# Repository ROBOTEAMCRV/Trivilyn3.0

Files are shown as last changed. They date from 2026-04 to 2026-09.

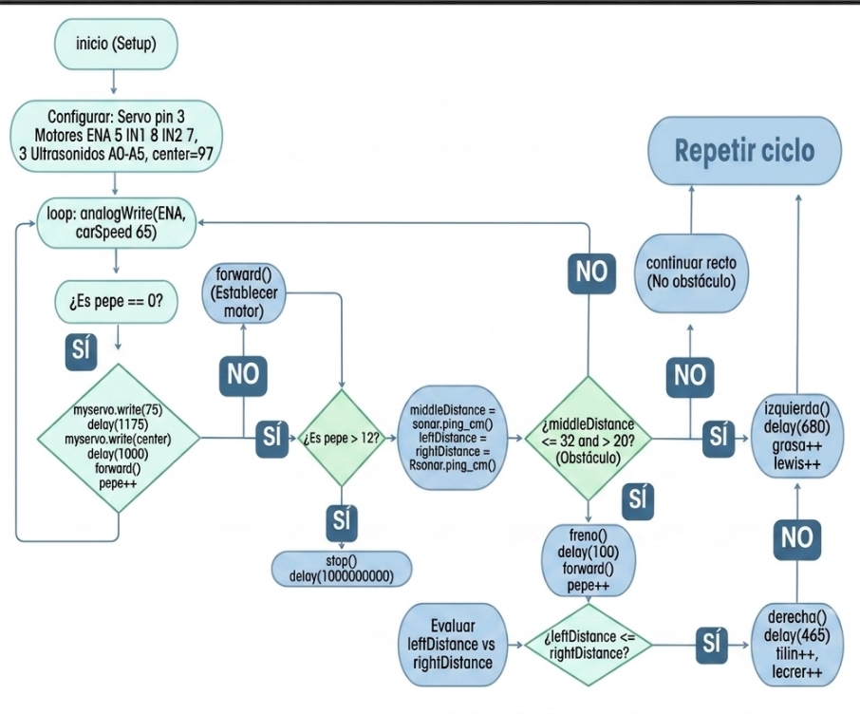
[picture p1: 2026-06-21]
Schematics/Diagrana de Flujo-Open Challenge.jpeg

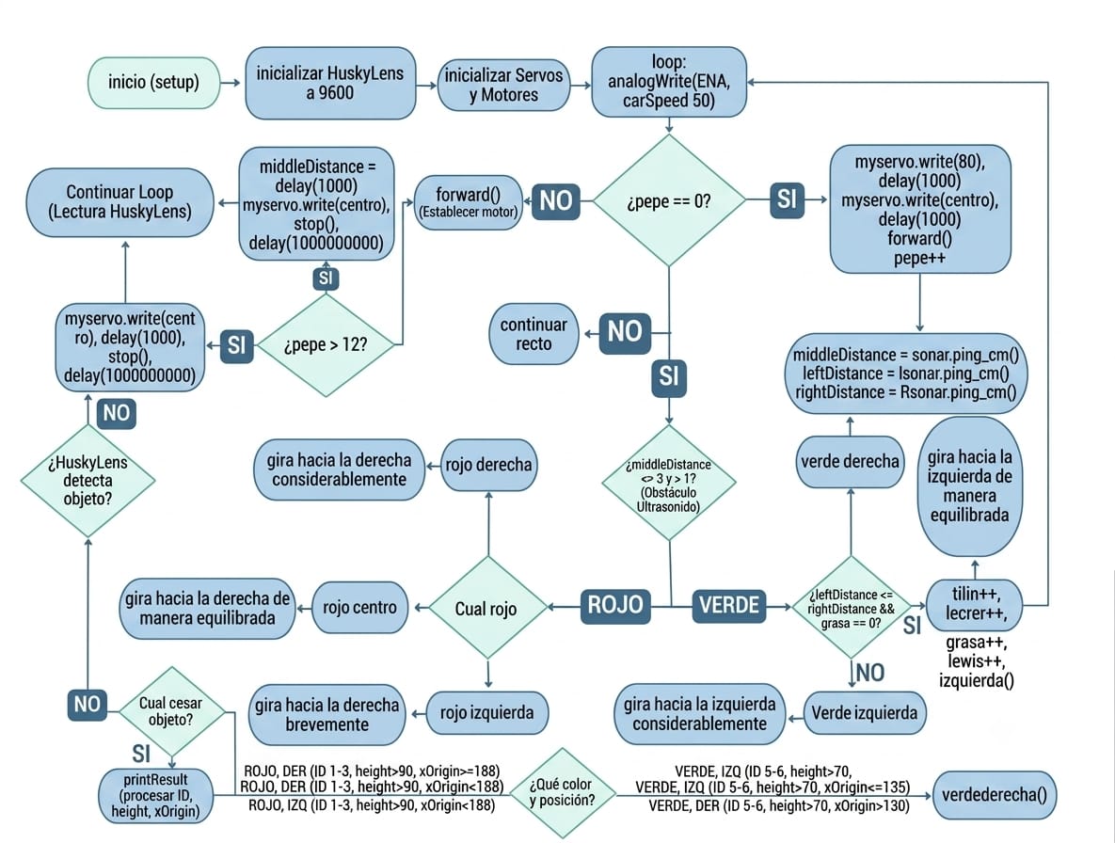
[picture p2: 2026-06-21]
Schematics/Diagrama de Flujo-Closed Challenge.jpeg

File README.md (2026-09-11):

# Engineering Document/Trivilyn3.0 

Nuestro prototipo es un vehículo autónomo diseñado para la categoría futuros ingenieros temporada 2026 WRO. En el que el equipo combina sus conocimientos y destrezas en la robótica(Mecánica, Electrónica, programación y automatización)  para la elaboración de (Trivilyn) y lograr el máximo desempeño en la categoría.



# ÍNDICE

## 📌Tabla de Contenido

1. [Engineering Document](#engineering-documenttrivilyn30)

2. [Miembros de TEAMROBOTICACRV](#miembros-de-teamroboticacrv)

   * [Dennis Adrian Silva Riera](#dennis-adrian-silva-riera)

   * [Gianni Marcello Martucci Jerez](#gianni-marcello-martucci-jerez)

   * [Juan Andres Graterol Teran](#juan-andres-graterol-teran)

   * [Tutor - Luis Eduardo Paredes](#tutor---luis-eduardo-paredes)
  
   * [Trivilyn 3.1](#trivilyn31)

3. [Fotos de Trivilyn 3.0](#trivilyn-360-photos)

4. [Movilidad y Diseño Mecánico](#-movilidad-y-diseño-mecánico)

   * [Tracción](#tracción)
  
   * [Calculo de Transmición](#cálculo-analítico-de-la-relación-de-transmisión)
   
   * [Estudio Dinámico: Torque Necesario, Tracción y Distribución de Fuerzas](#estudio-dinámico-torque-necesario-tracción-y-distribución-de-fuerzas)
  
   *  [Dirección](#dirección)
  
   * [Base Inferior](#primer-piso) 

   * [Base Cetral](#segundo-piso)

   * [Base Superior](#tercer-piso)
  
   * [Impresion 3D](#manufactura)
   
5.[Arquitectura de Potencia y Sensores](#-arquitectura-de-potencia-y-sensores)

   * [Subsistema Electrónico](#1-subsistema-electrónico)

   * [Esquemático Eléctrico](#30-documentación-e-ingeniería-del-esquemático-eléctrico)

   * [Distribución Geométrica y Calibración de Sensores](#distribución-geométrica-y-calibración-de-sensores)

   * [Sustentación de Valores Físicos en Pista](#-sustentación-de-valores-físicos-en-pista)

6. [Arquitectura de Software y Estrategia de Competencia](#arquitectura-software-y-estratrgia)

   * [Resumen del Proyecto](#-resumen-del-proyecto)

   * [Ronda Abierta](#ronda-abierta)
  
     * [Diagrama de Flujo](#-diagrama-de-flujo-open-challenge)

     * <a href="#maquina-estados"> Arquitectura del Software </a>
  
     * [Proceso de Pruebas/Ajustes](#d-bitácora-de-pruebas-y-lógica-del-código-open-challenge-reto-abierto)

     * [Análisis de Rendimiento](#análisis-de-rendimiento-optimización-de-tiempo-vs-fiabilidad)

   * [Ronda Cerrada](#ronda-cerrada-closed-challenge)
  
     * [Diagrama de Flujo](#-diagrama-de-flujo-closed-challenge)
    
     * [Proceso de Pruebas/Ajustes](#proceso-de-pruebas-y-ajustes-closed-challenge-ronda-cerrada-con-obstáculos)
    
     * [Mitigación de Fallas y Casos Extremos](#fallas-edgecases)
    
     * [Análisis de Rendimiento](#análisis-de-rendimiento-en-el-desafío-cerrado)
    
7. [Pensamiento Sistémico y Decisiones de Ingeniería](#pensamiento-sistémico-y-decisiones-de-ingeniería)

 - [Temporada 2024 (Rexbot 1.0)](#temporada-2024-rexbot10)

 - [Temporada 2025 (Rexbot 2.0)](#temporada-2025-rexbot20)

 - [Temporada 2026 (Trivilyn3.0)](#temporada-2026-trivilyn30)
     
   * [ Paradoja de la Masa del Sensor y la Inercia Rotacional)](#2-la-paradoja-de-la-masa-del-sensor-y-la-inercia-rotacional-i_z)

   * [Gestión de Fricción](#3-gestión-de-fricción-termodinámica-y-compatibilidad-química-de-materiales)

   * [Adaptabilidad Sensorial](#4-adaptabilidad-sensorial-ante-el-entorno-de-la-pista)

   * [Sistema de Corredera de Baterías](#5-sistema-de-corredera-de-baterías-y-optimización-cinemática)

   * [Evolución del Sistema de Interconexión](#6-evolución-del-sistema-de-interconexión-y-blindaje-de-señales-emi)
  
  - [Trivilyn3.1/Post regional](#trivilyn31)
       
8. [Desafíos Técnicos, Limitaciones y Soluciones en el Desarrollo](#desafíos-técnicos-limitaciones-y-soluciones-en-el-desarrollo)

    ## 📂 Estructura del Repositorio (Repository Directory Map)

Para agilizar la evaluación de los diferentes componentes del proyecto, puedes acceder directamente a los recursos y subcarpetas principales a través de los siguientes accesos directos:

* [Modelos Tridimensionales (Archivos CAD)](./Archivos%20CAD/)
  *Anclaje al repositorio central con los planos vectoriales nativos y archivos laminados segregados por pisos.*

* [Manual de Ensamblaje (Assembly Manual)](./Assembly%20Manual/)
  *Guía paso a paso con esquemas mecánicos para la construcción y calibración del chasis modular.*

* [Guía de Instalación (Instalación.md)](./Instalación.md)
  *Manual paso a paso para configurar el firmware, librerías y calibración electrónica del ESP32 desde cero.*

* [Planos y Circuitos (Schematics)](./Schematics/)
  *Acceso directo a la ingeniería electrónica del robot, incluyendo los diagramas de bloques, mapeo de pines (Pinout) y la red de distribución de potencia.*

* [Código Fuente (Src)](./Src/)
  *Firmware del vehículo autónomo, algoritmos Failsafe de filtrado y control de la máquina de estados.*

* [Galería de Identidad (Team-Photos)](./Team-Photos/)
  *Registro fotográfico oficial del equipo, fases de codiseño en el laboratorio y preparación.*

* [Renderizado Interactivo (Trivilyn 360)](./Trivilyn%20360/)
  *Modelos tridimensionales optimizados para visualización periférica completa y verificación geométrica.*

* [Desafíos en Pista (Videos)](./Videos/)
  *Registro audiovisual oficial de Trivilyn 3.0 ejecutando con éxito los desafíos de la competencia, demostrando en tiempo real la evasión de obstáculos y la estabilidad de los algoritmos de control.*

   ---
  
# MIEMBROS DE TEAMROBOTICACRV

## 👤Dennis Adrian Silva Riera

### Rol: Ingeniero Líder de Hardware e Integrador de Sistemas.

Diseño Mecánico: Se encarga del modelado en 3D de las piezas y el chasis, asegurando que todo sea ligero y funcional.

Electrónica: Responsable de conectar todos los componentes, la gestión de la batería y la ubicación estratégica de los sensores.

Gestión Digital: Administra el repositorio de GitHub y organiza toda la documentación técnica del proyecto.



## Historial de competición:

* **UVM 2023:** 
  * Quedé **Campeón** en la competencia de Sigue Líneas en la Universidad Valle del Momboy.
  * Recibí un reconocimiento por participar en el reto de Recolector de Obstáculos en ese mismo evento.

* **Temporada WRO 2024 (Con el equipo FVH):**
  * Obtuve el **1er lugar** en la competencia Estadal en la categoría de Innovación Junior.
  * **2do lugar** en el Regional de Los Andes.
  * **3er lugar** en el Regional WRO de la UCAB.
  * Cerre el año quedando en el **6to lugar** en la Final Nacional de la WRO 2024.

* **Olimpiadas Regionales Carabobo (ORC Valencia 2025):**
  * Competí con el equipo **TEAMROBOCRV** en el desafío de Sigue Líneas Creativas.

* **WRO Futuros Ingenieros 2025 (Con el equipo TEAMROBOCRV):**
  * Corrimos en las regionales de Caracas (Simón Bolívar) logrando el pase a la final.
  * En la **Final Nacional de la WRO 2025 nos montamos en el podio logrando el 3er Lugar de Venezuela**.

---

## 👤Gianni Marcello Martucci Jerez

### Rol: Programador y Desarrollador de Lógica de Navegación.

Algoritmos de Navegación: Desarrolla la lógica que permite al robot detectar obstáculos y decidir hacia dónde moverse de forma autónoma.

Arquitectura del Código: Organiza la estructura del programa para que sea eficiente y responda rápido ante cualquier cambio en la pista.



## Historial de competicion:

Este proyecto cuenta con la experiencia acumulada en boxes, quema de componentes en taller y la presión de haber representado al país en torneos internacionales. Este es el historial real en pista:

* **FIRST Competition 2022:**
  * Ganador del premio individual **The Best Roboticist 2022** en su debut en competencias grandes.

* **UVM 2023:** 
  * Quedé **Campeón** en la competencia de Sigue Líneas en la Universidad Valle del Momboy.
  * Recibi reconocimiento especial por el diseño en el reto de Recolector de Obstáculos.

* **Proyecto Asistente Farmacéutico:**
  * Ganamos el **1er lugar** en la competencia Estadal de Innovación y clasificamos para el Regional de Los Andes.

* **Temporada WRO 2024 (Con el equipo TEAMROBOCRV - Futuros Ingenieros):**
  * Pasamos de las eliminatorias regionales de Mérida y la UCAB.
  * En la **Final Nacional ganamos el Subcampeonato (2do lugar)** de Venezuela y el pase directo al mundial.
  * **Mundial WRO Turquía 2024:** Viajó a representar al país y logramos el **Puesto 48 del Mundo** en la categoría (Future Engineers).

* **Olimpiadas Regionales Carabobo (ORC Valencia 2025):**
  * Compitió en la categoría de Sigue Líneas Creativo con el equipo **TEAMROBOCRV**.

* **WRO Futuros Ingenieros 2025 (Con el equipo TEAMROBOCRV):**
  * Clasificamos en la Regional Simón Bolívar de Caracas.
  * En la **Final Nacional 2025 nos montamos otra vez en el podio logrando el 3er Lugar de Venezuela**.

---

## 👤Juan Andres Graterol Teran

### Rol: Especialista en Ensamblaje y Asistente de Operaciones.

Montaje Físico: Se encarga del armado manual del prototipo, asegurando que cada tornillo y pieza esté en su lugar.

Apoyo Logístico: Colabora en la preparación de las pistas de prueba, recolección de datos y mantenimiento preventivo del robot.



## Historial de competición:

* **UVM 2023:** 
  * Formó parte del equipo **Campeón** en la competencia de Sigue Líneas en la Universidad Valle del Momboy.
  * Recibió reconocimiento por su participación en el reto de Recolector de Obstáculos en el mismo evento.

* **Proyecto Asistente Farmacéutico:**
  * Ganador del **1er lugar** en la competencia Estadal de Innovación, logrando la clasificación y participación en el Regional de Los Andes.

* **Olimpiadas Regionales Carabobo (ORC Valencia 2025):**
  * Compitió con el equipo **TEAMROBOCRV** en el desafío de Sigue Líneas Creativas, trabajando directamente en las pruebas de agarre y estabilidad de chasis con dirección electrónica.

* **WRO Futuros Ingenieros 2025 (Con el equipo TEAMROBOCRV):**
  * Clasificó en la Regional Simón Bolívar en Caracas, peleando los mejores tiempos de la eliminatoria.
  * En la **Final Nacional de la WRO 2025 nos subimos al podio logrando el 3er Lugar de Venezuela** en la categoría.

---

## 👤Tutor - Luis Eduardo Paredes

### Rol: Orientar al equipo en la planificación del proyecto y el cumplimiento de los plazos de entrega.



 ##  👤Trivilyn3.1

 ### Rol: Vehículo Autónomo de Competición - Plataforma Oficial 2026.



  * **Estatura y Peso:** Estructura modular optimizada en tres niveles con una masa total controlada de 1150 gramos.
    
  * **Habilidades de Percepción:** Visión artificial acelerada por IA con HuskyLens para reconocimiento colorimétrico y una red unificada de sensores ultrasónicos HC-SR04 para mapeo perimetral en tiempo real.
    
  * **Capacidad Motriz:** Dirección de alta agilidad basada en un sistema Steer-by-Wire (SbW) acoplado a un servo HobbyPark de 35 kg con giros de 40°, impulsado por un motor DC de alta revolución con caja reductora personalizada.
    
  * **Dieta Energética:** Sistema de alimentación triple e independiente basado en celdas 18650.
> [!NOTE]
> **Nota de Evolución y Origen del Nombre:** Es importante aclarar que la nomenclatura **Trivilyn 3.0** Y **Trivilyn 3.1** representa la tercera generación de nuestra plataforma de competencia, siendo la evolución tecnológica directa de los prototipos anteriores **Rexbot 1.0** y **Rexbot 2.0** (no existen versiones 1.0 o 2.0 bajo el nombre de Trivilyn). El cambio de nombre y el término "Trivilyn" fue acuñado formalmente como un homenaje al apodo de cariño con el que nuestro tutor se refiere al equipo.

# Trivilyn 360 Photos

Para evidenciar la simetría, la distribución modular en tres niveles y el acabado de la manufactura aditiva del vehículo, se presenta la galería oficial en un formato de matriz técnica:

| 📸 Perfil de Inspección | 🖼️ Registro Visual (Render / Captura) |
| :--- | :--- |
| **Vista Superior**<br>• Permite evaluar la distribución de los componentes en el segundo piso y la alineación central. | Perfil Superior |
| **Vista Lateral Derecha**<br>• Muestra el despeje sobre el suelo (*ground clearance*) y el acople del tren motriz. | Perfil Derecho |
| **Vista Lateral Izquierda**<br>• Expone el acceso al sistema perimetral de alimentación y cableado lógico. | Perfil Izquierdo |
| **Vista Frontal**<br>• Muestra la orientación de la HuskyLens, el soporte de sensores y la matriz ToF. | Perfil Delante |
| **Vista Trasera**<br>• Evidencia el anclaje del motor principal y la salida estructurada de las líneas de potencia. | Perfil Trasero |
| **Vista Inferior (Chasis)**<br>• Expone la geometría del primer piso y el área libre para evitar la fricción con la pista. | Perfil Inferior |
---

# 🔩 Movilidad y Diseño Mecánico

El chasis de Trivilyn3.0 ha sido desarrollado desde cero utilizando un sistema híbrido de manufactura aditiva con polímeros avanzados (PETG y PLA), configurado en una estructura modular de tres niveles que optimiza al máximo el espacio y el centro de masa del vehículo. Cada pieza ha sido calculada para absorber las vibraciones mecánicas de la alta competencia, garantizando la rigidez necesaria para que los algoritmos de visión artificial operen con total precisión.

---

Este capítulo desglosa los principios físicos, cinemáticos y de distribución de fuerzas que gobiernan la movilidad de Trivilyn3.0, demostrando cómo se logra un control milimétrico del vehículo mediante un sistema de dirección Steer-by-Wire (SbW), una caja reductora a medida de alta eficiencia y una gestión inteligente del peso.

## Tracción:

- La tracción del prototipo esta constituido por 4 ruedas de goma extraídas de un kit de lego EV3, estas tienen como medida del neumático es de 43mm de diámetro exterior y su respectiva llanta(rin) 29mm.



* Anteriormente(Rexbot1.0), el prototipo utilizaba ruedas plásticas rígidas de mayor diámetro.
  


Sin embargo en 2025 para para Rexbot2.0 y actualmente la temporada 2026 para Trivilyn3.0, se decidió utilizar las ruedas de goma de 43 mm por las siguientes ventajas técnicas:

Mejora de Tracción: El compuesto de caucho del kit EV3 ofrece un coeficiente de fricción superior, eliminando el deslizamiento en aceleraciones rápidas.

Optimización del Centro de Gravedad: Al reducir el tamaño de las ruedas respecto a las versiones anteriores, se logró bajar el chasis, aportando mayor estabilidad en las curvas cerradas y evitando volcamientos.

Torque Efectivo: Un diámetro menor permite que el motor DC trabaje con una carga menor, logrando una respuesta de arranque más ágil y precisa.



## ¿Como logramos que se mueva con un solo motor?

Esto se logra mediante una caja de engranajes realizada a medida, que posee un eje tipo cruz basado en los que vienen en los kits de Lego, hechos de acero con medidas de 2.8 mm de ancho y 4.2 mm de alto; su longitud es de 119 mm. Tiene un refuerzo de teflón industrial alrededor del eje para evitar ser doblado o pandeado por el peso del prototipo.

### Análisis de Resistencia a la Fatiga por Torsión y Cizalladura Compleja
Al reducir las 15,000 RPM nominales del motor mediante una relación masiva de 78:1, el torque en el eje de acero se multiplica exponencialmente. Para garantizar la integridad estructural de la barra de 2.8 mm x 4.2 mm, se evaluó el esfuerzo cortante torsional máximo ($\tau_{max}$) mediante la fórmula de torsión para secciones no circulares:

$$\tau_{max} = \frac{T}{\alpha \cdot b \cdot t^2}$$

*Donde:*
* **$T$:** Torque multiplicado por la caja reductora ($\approx 0.158 \text{ Nm}$).
* **$b$ y $t$:** Dimensiones de la sección transversal del eje de acero.
* **$\alpha$:** Factor de forma geométrico para perfiles rectangulares.

El encamisado perimetral de **Teflón Industrial (PTFE)** actúa como un cojinete de soporte continuo que absorbe los momentos flectores parásitos inducidos por las irregularidades de la pista. Al tener un coeficiente de fricción extremadamente bajo, el PTFE impide el pandeo elástico del acero sin introducir resistencia por rozamiento, evitando que el eje sufra fatiga mecánica por flexotorsión tras múltiples rondas de operación a máxima potencia.

La caja reductora o caja de engranajes esta conformada internamente por 3 engranejes 
 

- Trivilyn se desplaza gracias a lo mencionado anteriormente, pero el que se encarga de dar el inicio del movimiento es un motor DC de 3 a 6 voltios, logrando entre 13 mil y 15 mil RPM.



Esta insertado en la parte lateral de la caja de engranajes de la siguiente manera



Aclaramos que estos motores se extrajeron de un turbo snake 



y se pueden extraer de distintos tipos de vehículos a control remoto como:

* **Vehículos Acrobáticos Tipo "Stunt" o Doble Cara (Genéricos de Amazon/AliExpress):** Diseñados para maniobras de alto impacto y giros de 360 grados. Sus motores internos poseen un torque de arranque elevado, ideal para romper la inercia inicial en prototipos que superan la línea de los 1000 gramos de masa.

---

* **Modelos de Competición Escala Mini 4WD (Tipo Tamiya):** Estos kits emplean motores ultra estandarizados (como la serie Mabuchi 130). Destacan por su ligereza, imanes de alta calidad y un régimen de revoluciones por minuto masivo, lo que facilita su acoplamiento directo en cajas reductoras diseñadas a medida.

---

* **Automóviles de Fricción de Escala Mayor (Tipo Maisto o Similares):** Aunque carecen de electrónica de radiofrecuencia, los mecanismos internos de estos vehículos albergan conjuntos de engranajes y motores de inercia pesados. Son una excelente fuente de componentes mecánicos y bobinados de alta durabilidad para resistir la fatiga por uso continuo.

---

* **Vehículos de Radio Control Semiprofesionales (Escala 1:24 o 1:16):** Modelos comerciales que, al sufrir fallos en sus placas lógicas principales, dejan intactos motores de las series 130 o 180. Estos componentes ofrecen una estabilidad térmica superior y un consumo de corriente optimizado bajo cargas de trabajo constantes.

Este motor es el corazón del desplazamiento y uno de los componentes principales para que Trivilyn tenga su desempeño. 

## ¿Por qué elegimos este motor? (Justificación de Boxes)

Para el sistema de tracción de Trivilyn 3.0 decidimos dejar de lado los típicos motores amarillos comerciales con reductoras plásticas integradas. Esos motores son geniales para empezar, pero en el nivel de exigencia de la WRO se quedan cortos en velocidad y tienen demasiado juego mecánico en los piñones. En su lugar, apostamos por un motor de corriente continua (DC) de alta velocidad tipo Mabuchi 130 (el famoso Turbo Snake), que levanta entre 13,000 RPM y 15,000 RPM en vacío. 

Para nosotros, usar un motor tan rápido y pequeño no fue una casualidad, sino una decisión de diseño basada en tres razones clave:

#### 1. Menos peso atrás significa giros más rápidos (Relación Potencia-Masa)
En la pista, cada gramo cuenta. Si poníamos un motor industrial grande o uno de pasos con reductora metálica pesada en el eje trasero, el robot iba a tener demasiada inercia en la cola, lo que haría que derrapara hacia los lados al intentar esquivar los bloques a alta velocidad. 
* **Nuestra solución:** El Mabuchi 130 pesa apenas 20 gramos. Al combinar este peso pluma con la caja reductora de tres etapas (78:1) que diseñamos e imprimimos nosotros mismos en PETG, logramos una fuerza de empuje brutal en las ruedas sin penalizar el peso del carro. Así mantenemos el robot completo en unos ágiles 1250 gramos de peso total.

#### 2. Cuidar la batería y evitar el sobrecalentamiento
Cuando un motor se esfuerza demasiado porque va muy lento o el carro es muy pesado, el consumo de corriente se dispara por las nubes. Esa energía extra se convierte en calor por el famoso efecto Joule, lo que puede derretir los soportes de plástico o quemar el driver.
* **Trabajar relajados:** Gracias a que nuestra caja reductora multiplica la fuerza 78 veces, el motor hace un esfuerzo mínimo en su propio eje para mover el carro. Al exigirle tan poco torque en el piñón de salida, el motor trabaja en su zona de máxima eficiencia: consume muy poca batería, el puente H trabaja frío y el voltaje de las celdas 18650 se mantiene estable durante todas las rondas de la competencia.

#### 3. Una respuesta al acelerador instantánea (Control por PWM)
Los motores que ya vienen con reductoras lentas suelen ser muy toscos; tardan en arrancar y cuando les quitas el voltaje se quedan rodando por inercia, lo que hace que el carro se pase de largo en las líneas.
* **Control milimétrico:** Como el rotor de este motor es pequeñísimo, casi no tiene inercia propia. Esto significa que si el código PID le pide frenar o acelerar, el motor responde en milisegundos. Calibramos el avance del coche a un valor de PWM 190 (que es más o menos el 74.5% de la potencia total). Con esto logramos el equilibrio perfecto: el robot vuela en las rectas, pero tiene un "freno de motor" inmediato cuando el ciclo baja a cero, permitiendo que Trivilyn 3.0 esquive los pilares de color sin perder el control ni una sola vez.

## Análisis Cinematómico y Dinámico del Tren de Engranajes (Caja Reductora 78:1)

Para vencer la inercia del chasis impreso en PETG y maximizar el torque en el eje motriz trasero, Trivilyn 3.0 implementa una caja reductora de eje compuesto de tres etapas con trenes de engranajes de dientes rectos. El sistema utiliza una configuración de piñones con conteos de dientes específicos de **8, 30, 5, 26, 5 y 20 dientes** para lograr una optimización del momento torsor.

### Cálculo Analítico de la Relación de Transmisión

La relación de reducción total se calcula multiplicando las relaciones de transmisión individuales de cada una de las tres etapas de engranajes en cascada:

* **Etapa 1 (Piñón del Motor a Engranaje Intermedio 1):** Con un piñón conductor de 8 dientes y un engranaje conducido de 30 dientes:
  **R1 = 30 / 8 = 3.75**
  *La velocidad angular se reduce 3.75 veces, incrementando el torque en la misma proporción.*

* **Etapa 2 (Piñón Intermedio 2 a Engranaje Intermedio 3):** Con un piñón conductor coaxial de 5 dientes y un engranaje conducido de 26 dientes:
  **R2 = 26 / 5 = 5.2**
  *La velocidad remanente de la primera etapa sufre una reducción adicional de 5.2 veces.*

* **Etapa 3 (Piñón Intermedio 4 a Engranaje del Eje Diferencial):** Con un piñón conductor de 5 dientes y un engranaje conducido final de 20 dientes:
  **R3 = 20 / 5 = 4.0**
  *La última etapa reduce el vector de velocidad 4 veces más antes de transferir la energía a las ruedas.*

* **Cálculo de Reducción Total (R_total):**
  **R_total = R1 x R2 x R3 = 3.75 x 5.2 x 4.0 = 78**

Esto establece una **Relación de Reducción Nominal de 78:1**. Por cada 78 rotaciones completas del eje del motor de alta velocidad (15,000 RPM), el eje motriz de las ruedas de caucho de 43 mm ejecuta una sola revolución, transformando la velocidad angular en fuerza de tracción neta en pista.

---

### 2. Análisis de Rendimiento Dinámico: Velocidad vs. Torque Real

Para proyectar el rendimiento real del prototipo en pista, se evalúa el efecto del tren de reducción sobre los vectores cinemáticos de salida. No obstante, el cálculo real debe considerar el **coeficiente de eficiencia mecánica (Eficiencia Global)**, el cual modela las pérdidas de energía por fricción parásita, calor por rozamiento y desalineaciones menores en el chasis.

| Parámetro Cinematómico | Efecto Físico de la Reducción | Ecuación Estructural Teórica |
| :--- | :--- | :--- |
| **Velocidad Angular (n_salida)** | **Disminuye de forma lineal** 78 veces respecto a la velocidad de entrada del motor. | **n_salida = n_entrada / 78** |
| **Torque Neto (M_salida)** | **Aumenta de forma proporcional** 78 veces, multiplicado por la eficiencia de transmisión. | **M_salida = M_entrada x 78 x Eficiencia** |

*Donde:*
* **n_entrada:** Velocidad del motor Turbo Snake en vacío (aproximadamente 15,000 RPM).
* **M_entrada:** Torque nominal instantáneo generado por el eje del motor.
* **Eficiencia Global del Tren:** Estimada analíticamente en un **85%** (0.85) para engranajes rectos de tres etapas acoplados sobre bujes de bronce, absorbiendo las pérdidas por fricción termodinámica.

---

### 3. Justificación Mecánica de la Configuración 78:1

> [!NOTE]
> **El Compromiso Velocidad/Fuerza (Trade-off):**
> Un motor que opera directamente a 15,000 RPM patina instantáneamente en las curvas debido a la falta de torque estático, quemando el puente H por sobrecorriente. La reducción de 78:1 reduce la velocidad en el eje de la rueda a unas manejables e hiperestables **192 RPM bajo carga máxima**, dotando a Trivilyn 3.0 de la fuerza necesaria para mantener la aceleración constante en las curvas cerradas y garantizando que las ruedas de 43 mm mantengan el agarre mecánico (grip) sin pérdidas por derrape lateral.

## Estudio Dinámico: Torque Necesario, Tracción y Distribución de Fuerzas

Para asegurar que el motor de tracción (extrayendo el núcleo de un Turbo Snake) sea capaz de romper la inercia del vehículo a máxima aceleración, evitar el estancamiento térmico (stall) y optimizar el agarre en pista, desarrollamos un modelo matemático basado en las especificaciones físicas reales de **Trivilyn 3.0**:

* **Masa Total del Vehículo:** 1150 gramos = 1.15 kg
* **Peso Total:** 1.15 kg * 9.81 m/s² ≈ 11.28 Newtons
* **Radio de las Ruedas Traseras:** Diámetro de 43 mm / 2 = 21.5 mm = 0.0215 metros
* **Relación de Reducción de la Caja:** 78:1 (Caja reductora a medida con ejes de acero)

---

### 1. Cálculo del Torque Estático Mínimo en las Ruedas (Breakout Torque)

El torque mínimo necesario en el eje de las ruedas traseras para vencer la fricción estática del caucho contra la superficie de la pista (asumiendo un coeficiente de fricción estática conservador mu_s ≈ 0.6) se calcula mediante la relación:

Torque_ruedas = Peso * mu_s * radio

Torque_ruedas = 11.28 N * 0.6 * 0.0215 m ≈ 0.1455 Nm = 1.484 kg-cm

* **Multiplicación por la Caja Reductora (78:1):** Gracias a la reducción mecánica fabricada por el equipo, el torque que el motor Turbo Snake necesita entregar en su piñón de entrada es extremadamente bajo:

Torque_motor = Torque_ruedas / Relación_Reducción = 1.484 kg-cm / 78 ≈ 0.0190 kg-cm

* **Conclusión Mecánica:** Operar el motor bajo la línea sobreelevada de 10V estables garantiza que trabaje en la zona de máxima eficiencia de su curva de potencia, logrando aceleraciones explosivas a PWM 190 sin riesgo de sobrecalentamiento en las bobinas o deformación térmica del soporte de PETG.

---

### 2. Distribución de Carga y Centro de Masas Estratégico

La distribución del peso de los 1150 gramos se planificó de forma asimétrica pero controlada a través de la arquitectura de pisos, logrando un balance de fuerzas óptimo para un vehículo de tracción trasera (RWD):

```text
               DISTRIBUCIÓN DE FUERZAS E INERCIA (TRIVILYN 3.0)
               
      [Tren Delantero]                                  [Tren Trasero]
    (Dirección SbW/Servo)                         (Tracción/Motor/Baterías)
           │                                                 │
           ▼                                                 ▼
     35% del Peso (~402.5g)                            65% del Peso (~747.5g)
  [Baja inercia angular para]                       [Máxima Fuerza Normal (N)]
    [giros rápidos de 40°]                       [Elimina el derrape / Grip total]
```

 

* **Eje Trasero (65% de la Masa ≈ 747.5g):** Al alojar el motor, la caja de engranajes y el cartucho de cola de milano en la parte posterior inferior, se maximiza la Fuerza Normal sobre las ruedas de goma. A mayor fuerza normal, mayor es la fuerza de tracción máxima utilizable antes de que las ruedas patinen en el arranque.
* **Eje Delantero (35% de la Masa ≈ 402.5g):** Al fijar la electrónica y los sensores en el segundo y tercer piso de forma retrasada, el tren delantero queda lo suficientemente ligero como para que el servomotor de 35 kg rompa la fricción lateral de forma instantánea, logrando cambiar el ángulo de ataque a 40° por lado en milisegundos sin arrastrar el frente del carro.
  
  ---
  
La caja de engranajes mencionada anteriormente se sostiene con una base diseñada en 3D por el equipo. (Recordamos que los diseños como este se encuentran en el apartado de Archivos CAD).



Esta base funciona como una especie de tapa y abrazadera realizada a medida, evitando vibraciones y fallos para sostener toda la tracción trasera de Trivilyn; encaja con los soportes del eje trasero principal, siendo así las partes laterales de la caja de engranajes y la parte central de la caja de engranajes.



que al lograr encajar con el sistema de engranajes se fija a la primera base de Trivilyn por 4 tornillos

Si se puede observar el soporte en la parte inferior tiene una especie de “Vena” 



Es una extencion de filamento cuya funcion es solucionar que en versiones anteriores de este soporte se fracturaba esa zona problema que resuelve esta “vena” que actúa como un refuerzo y proporciona varias ventajas como:

- La vena añade una estructura perpendicular o diagonal que "amarra" las capas principales. Al tener una geometría curva, las líneas de extrusión de la impresora envuelven la pieza, creando una especie de "esqueleto" externo que mantiene las capas unidas bajo presión.

- Esto hace que la pieza sea mucho más resistente a la flexión. En un robot de competencia, los motores y el movimiento generan vibraciones; la vena asegura que el soporte se mantenga rígido y no "oscile", lo cual terminaría quebrando el PETG.

## Dirección: 

La movilidad en la parte delantera: aquí nos referimos al sistema de dirección (control de giros del robot), ruedas frontales y todos los componentes de estos para unirse entre sí.

Para esta parte de Trivilyn3.0 nos basamos en la plataforma estable de Trivilyn 2025; Para esta temporada 2026 hemos conservado el sistema de dirección por su alta confiabilidad, pero hemos aplicado dos optimizaciones críticas en la respuesta dinámica y la durabilidad de los materiales, las cuales son:

1.Principalmente imprimimos los componentes nuevamente en PETG porque es un material mas resistente al desgaste y posibles fracturas que el PLA.

El **PETG (Tereftalato de Polietileno Glicol)** es un copoliéster termoplástico ampliamente utilizado en la manufactura aditiva (impresión 3D) de componentes robóticos estructurales y de alta resistencia. A diferencia del PLA convencional, el PETG destaca por su excelente balance entre tenacidad, flexibilidad y resistencia química, lo que lo convierte en el polímero ideal para soportar los esfuerzos dinámicos y las vibraciones mecánicas dentro del chasis del vehículo autónomo.

### ¿Por qué PETG?

- Durante la competencia, los motores DC y los drivers de potencia generan calor. El PLA puede empezar a ablandarse o deformarse si está cerca de una fuente de calor constante o si el robot se deja bajo el sol/luces intensas del evento. El PETG mantiene su integridad estructural.

- El PETG es más "tenaz" (ductilidad). Tiene la capacidad de absorber energía deformándose elásticamente antes de romperse. En un choque, una pieza de PETG tiene más probabilidades de flexionarse y volver a su forma, mientras que una de PLA se rompería, dejando al robot fuera de la competencia.

- El PLA es biodegradable y sensible a la humedad (higroscópico), lo que puede degradar sus propiedades mecánicas con el tiempo. El PETG es resistente al agua y a muchos químicos, lo que garantiza que las piezas del robot no se vuelvan quebradizas meses después de haber sido impresas.

2.Se Realizo un cambio al tubo transversal.Este cambio del del tubo consiste en su material no en sus medidas o forma, decidimos hacerlo de bronce en un torno por las principales ventajas:

- En la version anterior el tubo era de plastico.El plástico contra plástico genera mucha fricción y calor, lo que provoca que los ejes de LEGO se desgasten ("se limen") con el tiempo, perdiendo su forma de cruz.

- Al ser un material con propiedades autolubricantes, el bronce actúa como una superficie de sacrificio suave. Es mucho más amigable con el plástico que otros metales o que el propio roce plástico-plástico.

- El tubo de bronce aporta una rigidez estructural externa. Al encamisar o soportar el eje con bronce, obliga al eje a mantenerse recto, asegurando que toda la fuerza del servo llegue a las ruedas sin pérdidas por flexión.

- Los conectores de plástico suelen tener tolerancias holgadas (pequeños movimientos flojos).Cosa que no nos podemos permitir para una competencia como la WRO, ese pequeño juego hace que el robot "baile" en las rectas y reduce la precision.



### Modelo de Interfaz Tribológica y Mitigación del Backlash
La sustitución del tubo plástico por un buje de bronce maquinado en torno responde a principios de **Tribología Mecánica** (ciencia que estudia la fricción, el desgaste y la lubricación de superficies en contacto relativo). El acoplamiento entre el eje de acero y el alojamiento de bronce establece un par cinemático de alta eficiencia con las siguientes propiedades:

* **Coeficiente de Fricción Estática Reducido:** La aplicación de vaselina industrial sobre la superficie de bronce crea una película hidrodinámica microscópica. Esto reduce el coeficiente de fricción a rangos menores de $\mu \approx 0.05$, anulando el desgaste por fricción seca.
* **Supresión Absoluta del Juego Flotante (*Backlash*):** Los conectores comerciales plásticos poseen tolerancias holgadas de hasta $\pm 0.4 \text{ mm}$ para facilitar el ensamble manual, lo que provoca que el robot oscile de forma errática (*drifting*) en tramos rectos. El maquinado micrométrico del bronce restringe los movimientos parásitos en los ejes radiales a menos de $\pm 0.02 \text{ mm}$, garantizando que cada micro-pulso PWM enviado al servomotor de 35 kg se traduzca en un cambio angular idéntico y predecible en las manguetas del vehículo.

---

Ya teniendo claro esto, podemos iniciar con explicar: ¿qué hace que se mueven las ruedas frontales? El encargado de esto es un servomotor que está fijado a la base principal de Trivilyn con sus respectivos tornillos y tuercas. Este servomotor no es convencional como los modelos SG90 o MG95; Es un servomotor HobbyPark de 35 kg (Modelo HD3523MG). Sistema de movimiento que se implementó en Rexbot 2.0 y decidimos conservar esta parte, ya que cumple su función de manera precisa.

Especificaciones del servomotorHobbyPark 35kg (Modelo HD3523MG):

Torque (Fuerza):
* A 6.0V: ~29 kg-cm
* A 7.4V: ~35 kg-cm
* Velocidad:
* A 6.0V: 0.14 seg / 60°
* A 7.4V: 0.12 seg / 60°
* Voltaje de operación: 6.0V a 8.4V (soporta baterías LiPo 2S directamente).
* Tipo de motor: Coreless (sin núcleo), lo que permite una aceleración más rápida y un funcionamiento más suave que los motores estándar.

Engranajes: Metálicos de alta precisión (Stainless Steel & Aluminum). Esto es lo que le permite manejar los 35kg de presión sin romperse.

Carcasa: Aluminio CNC, Ayuda a disipar el calor del motor durante uso intensivo.

Rodamientos: Doble rodamiento de bolas para reducir la fricción en el eje principal.

Ángulo de control: Generalmente 180° o 270° (según la configuración de fábrica, pero es programable).



Que el equipo adquirido en Amazon. ¿Por qué no se usan servos convencionales? Esto tiene un motivo, ya que utilizamos versiones más convencionales en prototipos anteriores de nuestro robot. (El porqué de esta decisión y los retos por los que tuvo que pasar el equipo para tomar esta decisión se pueden conseguir más a detalle en el apartado de «Pensamiento sistémico y decisiones de ingeniería: [Temporada 2025](#temporada-2025-rexbot20)).

## Tipo de Direccion y Como funciona

- Este contiene un sistema de dirección (Steer-by-Wire) que cada rueda puede moverse independientemente, aunque están montadas en un eje común (lo cual sugiere una posible adaptación diferencial) Ya que la rueda interior gira ligeramente más que la otra, de modo que el robot se mantiene en el mismo arco sin deslizamiento. (Derrape). 

- Con este sistema de direccion, logramos obtener resultados de que trivilyn logre un giro con angulo de 80 grados(40° por lado)

Para validar el comportamiento mecánico del sistema **Steer-by-Wire (SbW)**, se documentó el puente de dirección en sus tres estados fundamentales. El actuador HobbyPark de 35kg modifica el ángulo de ataque de las ruedas sin juego mecánico visible (*backlash*).

| Registro Fotográfico | Estado de Giro | Ángulo | Descripción de la Dinámica en Pista |
| :---: | :--- | :---: | :--- |
| Giro Izquierda | **Viraje Absoluto a la Izquierda** | ~30° a 40° | El puente se desplaza en sentido horario para correcciones críticas y curvas cerradas. |
| Dirección Neutra | **Posición Neutra (Línea Recta)** | 0° | El puente se alinea de forma perpendicular al chasis. Estado de mínima fricción y máxima aceleración. |
| Giro Derecha | **Viraje Absoluto a la Derecha** | ~30° a 40° | El puente se desplaza en sentido antihorario para evasión rápida de obstáculos y señales. |

### 🛠️ Justificación Técnica del Sistema SbW

1. **Optimización del Radio de Giro Real:** El rango extendido de 40° por lado permite que el robot complete maniobras de evasión y estacionamiento en espacios confinados, solucionando de raíz las limitaciones de agilidad geométrica presentes en los antiguos prototipos de la serie Rexbot.
2. **Mitigación del Desgaste y Derrape:** Al forzar mecánicamente la divergencia de las ruedas durante el viraje (Ackermann), se reduce la fricción parásita de las llantas contra la superficie de rodadura, optimizando el consumo del Power Budget y garantizando un avance fluido.
3. **Control Predictivo y Calibración:** Al no depender de varillajes mecánicos complejos expuestos a holguras físicas, las desviaciones milimétricas de la dirección se corrigen directamente mediante software de control en milisegundos, asegurando un comportamiento idéntico tanto en sentido horario como antihorario de la carrera.

---

>[!IMPORTANT]
> **Calibración del Punto Neutro en el Firmware:**
> Al inicializar la máquina de estados en el Arduino Mega, el pulso PWM enviado al servo HobbyPark debe ajustarse exactamente al valor de microsegundos que garantice la perpendicularidad perfecta mostrada en el estado neutro. Cualquier desviación física milimétrica en el acople se corrige mediante el software de calibración de compensación para evitar derivas (*drifting*) en tramos rectos.

- siendo así mas ágil para llegar a cumplir sus objetivos, (giros a gran velocidad, sortear objetos de manera optima, salir del estacionamiento en paralelo).

---

Para lograr la adaptación del servo a las ruedas, utilizamos piezas en 3D diseñadas por nosotros, lego y acero, esta consiste en 3 partes principales:

1. Encaje de palanca de acero a base en 3D

Esta base fue rediseñada varias veces hasta que logramos encontrar el punto donde no se deformara por el peso y, también, para que encajara perfectamente la pieza de hierro a presión y evitar todo el juego posible (imprecisión de los componentes).

2.Luego de encajar esta pieza, utilizamos un tipo de abrazadera, que sostiene el buje del eje con forma de cruz extraido de un kit Legoeo EVE3

3.Para centrar y estabilizar su eje utilizamos retenes de lego amarillos 



Dos por la parte interior y uno por la parte exterior por cada lado. Estos se encargan de sujetar los ejes de las ruedas al sistema de dirección; luego, el diferencial «tubo transversal», ya antes lubricado con vaselina.

# 🏗️ Arquitectura Modular: Desglose Estructural por Pisos

# Primer piso

La base inferior al igual que las demas piezas de Trivilyn3.0 esta realizada en impresión 3D del material PETG de la marca Creality el cual adquirimos de la tienda oficial de Creality ubicada en Caracas 



La base tiene unas medidas de 90mm de ancho × 170mm de largo x 48mm de alto 



con una forma innovadora en su diseño como las líneas de relieve en la parte superior



Estas cumplen una función muy importante en el diseño de manera directa la cual es dar mayor rijides a la base para evitar deformaciónes o fracturas.Para esto el equipo se inspiro en las formas de los chasis de los vehiculos.

Aunque anteriormente nunca hemos tenido problemas con deformaciónes empleamos estos ("Refuerzos") para prevenir problemas en un futuro y Trivilyn3.0 pueda soportar cualquier irregularidad

Ya explicado esto se pueden observar:



Esta forma decreciente en la parte frontal de la base es el espacio necesario para que el sistema de dirección tenga una movilidad de 40° por lado, y fue diseñado de esta forma en base al sistema de dirección que implementamos en Trivilyn.

En la base se encuentran 9 orificios 8 para tornillos, 4 para el servomotor que poseen un ancho de 4.5mm que es la medidad del encaje de los tornuillos que trae el servomotor de fabrica.Todas estas medidas fueron realizadas por un vernier que funciona de la siguiente manera:

### Funcionamiento y Lectura del Vernier

- El vernier funciona mediante la superposición de dos escalas: la Regla Fija (milímetros) y el Nonio (la escala móvil que da la precisión decimal)

 

1. Lectura de la Escala Principal (Enteros)
Primero, observa dónde se ubica el cero (0) de la escala móvil (nonio) respecto a la regla fija.

- Si el cero del nonio pasó la marca de los 20 mm pero no llega a los 21 mm, tu medida base es 20 mm.

2. Lectura del Nonio (Decimales)

- Para obtener los decimales (el .2 mm), se debe buscar cuál línea del nonio coincide exactamente en una línea recta con cualquier línea de la regla fija.





- 4 tornillos para el soporte de la tracción trasera,utilizamos tornillos de 4mm en vez de otras medidas por lo siguiente razon:

- Esta decisión se basa en un análisis de resistencia a la cizalladura, ya que este componente soporta el torque reactivo de los motores. El diámetro de 4 mm ofrece una superficie de contacto superior con el chasis de PETG, minimizando la fatiga del material por vibración y garantizando que la geometría del tren motriz permanezca inalterada ante aceleraciones de alta intensidad.

- En piezas impresas en 3D, un agujero muy grande reduce el área de las paredes de relleno (infill), lo que puede debilitar estructuralmente el soporte en lugar de fortalecerlo. El M4 permite mantener una estructura sólida alrededor del tornillo sin comprometer la resistencia de la pieza impresa.

- El motor utilizado no generan el torque suficiente para romper un tornillo de acero M4. Por lo tanto, usar un M6 o M5 no aportaría ninguna seguridad extra real, solo penalizaría el rendimiento del robot.



El agujero más grande de todos con forma rectangular es el orificio donde se encaja el servomotor de la dirección con unas medidas de 40.2mm*20.2mm  

Esos 0.2mm extra en el diseño para el encaje de la pieza no son un error y su explicacion es la siguiente:

- Aunque se diseñe un hueco de 20 mm, el material alrededor de ese hueco tiende a contraerse hacia adentro mientras se enfría, reduciendo el espacio real disponible. Los 0.2 mm adicionales compensan esa contracción del polímero, asegurando que el componente mantenga un "ajuste deslizante" (clearance fit).

- Las impresoras 3D funcionan depositando cordones de plástico (extrusión). La boquilla (nozzle) suele ser de 0.4 mm, pero el plástico se aplasta ligeramente al salir.Este aplastamiento hace que las paredes internas de un hueco sean siempre unas micras más gruesas de lo que dicta el modelo digital. Al añadir 0.2 mm de tolerancia, estámos compensando el exceso de flujo (over-extrusion) y las irregularidades microscópicas de las capas (capas de 0.2 mm de altura), permitiendo que las superficies deslicen sin quedar atrapadas por la fricción de las capas.



Esta base, posee 3 pilares que se encargan de sostener el segundo piso posicionados estratégicamente 2 en la parte trasera y una en la parte frontal estás se encargan de soportar los demás pisos de Trivilyn



Sus medidas son de 7 mm de largo x 6.5 mm de ancho x 45 mm de alto y, en la parte inferior de cada pilar, se implementaron soportes en forma de rampa en la base de los pilares que sostienen el segundo nivel del chasis. Esta geometría de cartela estructural tiene como objetivo principal la triangulación de fuerzas, proporcionando rigidez ante los momentos flectores generados por la inercia del robot en fases de aceleración y frenado. El diseño inclinado no solo optimiza la distribución de cargas hacia el chasis principal, sino que mejora la viabilidad de la impresión en PETG al eliminar la necesidad de soportes externos, garantizando una unión mecánica superior entre niveles.



Para finalizar es necesario analizar la integración en el "primer piso" o chasis inferior del vehículo un sistema para la extracción de 1 par de baterias 18650 que se ubican en el. Este plano fundamental no solo actúa como el soporte rígido de la suspensión y los ejes de tracción, sino que ha sido diseñado geométricamente para encapsular el contenedor de baterías sin interferir con los actuadores ni comprometer la distancia al suelo ( distancia al suelo ).



El riel guía macho de la corredera está integrado directamente en la matriz del chasis inferior, ubicado en el espacio simétrico comprendido entre el eje de dirección delantero y el conjunto motor-reductor trasero. Esta disposición central asegura que el volumen de las celdas 18650 ocupa un espacio que básicamente no restringe el radio de giro de las ruedas delanteras ni la cinemática de los eslabones de dirección.

  

 Al formar parte del primer piso, el cartucho deslizable queda protegido perimetralmente por la estructura sólida del chasis impreso en PETG. Esto significa que las baterías no están suspendidas ni expuestas a impactos directos en caso de colisión; el chasis actúa como un exoesqueleto protector. Además, al situarse en el nivel más bajo, el peso del banco de energía se descarga directamente sobre los puntos de apoyo de los ejes, evitando flexiones mecánicas en las placas superiores del segundo y tercer piso.

-  La corredera macho cuenta con un tope mecánico en el extremo interno que alinea automáticamente los terminales de presión de las celdas con el bloque de distribución del primer piso. Desde este punto basal, las líneas de alimentación de alta corriente (conductores de calibre adecuado para soportar los picos del motor y el servo) ascienden de manera vertical y ordenada a través de pasacables integrados hacia el segundo piso, donde se conectan al interruptor general ya los módulos de regulación. Esto mantiene el primer piso libre de bucles de cableado sueltos que pueden atascarse con elementos externos de la pista o con el propio movimiento de la corredera.

## Especificaciones de Fabricación y Tolerancias Geométricas

- Material de Fabricación: Polímero de Polietileno Tereftalato Glicolizado ( PETG ). Se seleccionó este material sobre el estándar PLA debido a su alta resistencia al impacto, superior tenacidad y resiliencia ante esfuerzos mecánicos de flexión, además de su inmunidad química frente a agentes lubricantes industriales.

- Parámetros de Fabricación: Relleno de tipo giroscópico al 35% con 4 perímetros de pared exteriores. Esta configuración genera una estructura interna alveolar con una relación resistencia-peso óptima, capaz de absorber las vibraciones mecánicas de alta frecuencia del motor sin transmitir fatiga por esfuerzo a las uniones del chasis.

- Ajuste Mecánico del Riel: El canal hembra integrado en el chasis presenta una tolerancia geométrica de +0.2 mm respecto a la corredera macho de las baterías. Este margen de holgura de precisión es crítico: previene el juego mecánico o las oscilaciones del banco de energía durante las aceleraciones transversales, pero mantiene el coeficiente de fricción lo suficientemente bajo para permitir un deslizamiento manual suave y fluido.

## Mecanismo Deslizable en Corredera Lateral (Macho-Hembra)
El sistema de alimentación no utiliza contenedores fijos ni requiere el desmontaje de los niveles superiores. El sistema está compuesto por dos subconjuntos mecánicos interconectados:

Riel Macho Integrado: Una cavidad longitudinal con guías en ángulo de geometría trapezoidal (similar a una cola de milano invertida), extruida directamente en el centro geométrico del primer piso. Su ubicación interaxil aprovecha el espacio muerto comprendido entre el servo de dirección y el tren motriz trasero, optimizando la distancia libre al suelo a un valor constante de 15 mm .



Cartucho Hembra Porta-Celdas: Un contenedor compacto impreso en PETG que aloja firmemente dos celdas de litio de formato 18650 dispuestas en paralelo. Cuenta con ranuras laterales que se acoplan simétricamente al riel hembra del chasis y una pestaña ergonómica en el extremo exterior que facilita el agarre y la tracción manual para el operario.



________________________________________________________________________________________________________
### Explicación sistema Cola de Milano 

El diseño de la interfaz de deslizamiento entre el chasis inferior (riel macho) y el cartucho porta-celdas (riel hembra) implementa un perfil prismático con geometría de cola de milano (unión trapezoidal angular). Esta decisión de diseño sustituye a las guías planas tradicionales con el objetivo de aprovechar las propiedades mecánicas de auto-alineación y restricción de esfuerzos multiaxiales que ofrece esta configuración geométrica.



A diferencia de los rieles de sección cuadrada o en "T", donde las fuerzas de torsión se concentran de forma crítica en ángulos rectos de 90°(provocando zonas de alta concentración de esfuerzos y fracturas por cizalladura), la cola de milano distribuye las cargas a lo largo de planos inclinados (típicamente configuradas a un ángulo de flanco = 60°).Cuando el robot experimenta una fuerza centrífuga lateral a PWM 190, el flanco inclinado descompone la fuerza normal en componentes vectoriales, aumentando la fricción estática interna de contacto y bloqueando el conjunto firmemente en su sitio. Cuanto mayor es la fuerza que intenta separar el cartucho lateralmente, más se acuña la geometría dentro de su contraparte.La implementación de este sistema proporciona las siguientes ventajas:

- Al introducir el cartucho, la conicidad natural de los flancos laterales actúa como una guía autocentrante. Esto compensa pequeños errores de aproximación manual del operario bajo condiciones de estrés en competencia, encauzando mecánicamente el porta-celdas hacia los terminales eléctricos de fondo.

- Estabilidad de la Distancia al Suelo ( Ground Clearance ): Al quedar la junta entrelazada de forma interna, el espacio total ocupado por el mecanismo se reduce al espesor nominal del chasis, permitiendo un despeje constante de 15 mm respecto al suelo sin protuberancias externas que puedan encallarse en las imperfecciones de la pista.

- Compensación de Desgaste por Fricción: Las superficies anguladas se asientan mejor con el uso continuo. El sutil desgaste microscópico provocado por el ciclo de inserciones no genera holgura holgada (como ocurriría en un riel cuadrado), sino que permite que el cartucho se asiente de manera más íntima dentro del cono receptor.

>[!NOTE]
> Consideración de Tolerancia Crítica en Manufactura Aditiva (Impresión 3D) 
Al imprimir perfiles en cola de milano de forma horizontal, el fenómeno de la gravedad puede provocar un leve colapso de las capas superiores del riel hembra ( overhangs sin soporte). Para contrarrestar esto en Trivilyn3.0, el ángulo de los flancos se limitó estrictamente  60° respecto a la horizontal. Esto permite que las impresoras depositen el filamento PETG utilizando puentes térmicos autosoportados, manteniendo la fidelidad dimensional del canal intacta y eliminando la necesidad de soportes internos que arruinarían el acabado superficial y el coeficiente de fricción de la guía.

>[!TIP]
>Al preparar el código G ( G-code ) en el software de laminado (PrusaSlicer, Cura, etc.), la pieza matriz del chasis inferior (riel hembra) debe orientarse obligatoriamente de forma plana sobre la cama de impresión (planos de los ejes XY) .
>
>La importancia de esta configuración de fabricación radica en la física del material anisotrópico (las impresiones 3D son más débiles en la unión entre capas):
>
>- Alineación de Filamentos: Esta orientación garantiza que los hilos de plástico extruido corran de forma longitudinal, paralelos a la longitud del riel de la cola de milano.
>
>- Resistencia Estructural: Las fuerzas de tracción y cizallamiento laterales que ejerce el cartucho de baterías en las curvas cerradas actuarán de forma perpendicular a la deposición de las capas. Esto aprovecha la resistencia máxima del polímero PETG en su plano sólido molecular, eliminando por completo el riesgo de delaminación o desprendimiento de los rieles del primer piso durante la carrera.

## Topes Mecánicos y Retención Dinámica (Sistemas de Seguridad)

Para contrarrestar las fuerzas de inercia y la transferencia de carga transitoria durante frenados bruscos o cambios de dirección extremos a regímenes de alta velocidad (PWM 190), el diseño mecánico de Trivilyn3.0 incorpora dos sistemas de seguridad geométricos por hardware tolerantes a fallas:

* **Tope de Profundidad Trasero:** Una pared sólida dispuesta al final del riel macho que actúa como final de carrera física. Su función es detener el avance del cartucho móvil exactamente en el punto concéntrico donde los contactos de presión ejercen la interfaz eléctrica óptima con el bloque de distribución basal, evitando sobrecargas mecánicas en los terminales.
* **Sistema de Limitación por Pasador y Ranura de Seguridad:** Para evitar que el contenedor de energía se desprenda o sea expulsado por completo del chasis durante los mantenimientos de emergencia a alta presión en boxes, se diseñó una restricción prismática integrada. El riel hembra (solidario al contenedor de la batería 18650) incorpora un orificio cilíndrico pasante calibrado. A través de este agujero se introduce un tornillo de seguridad cuya punta sobresale internamente para acoplarse y navegar de forma concéntrica dentro de una ranura longitudinal tallada en el riel macho (ubicado en la base del primer piso).



## Interfaz de Conexión y Guiado de Cableado
Al formar parte del primer piso, el cartucho deslizable queda protegido perimetralmente por la estructura sólida del chasis, la cual actúa como un exoesqueleto protector ante colisiones. Desde el bloque de distribución basal, las líneas de alimentación de alta corriente (conductores de calibre adecuado para soportar los picos del motor de tracción y el servomotor de 35 kg) ascienden de manera vertical y ordenada a través de pasacables integrados hacia el segundo piso.

Esta disposición mantiene el primer piso completamente libre de bucles de cableado sueltos que pueden atascarse con elementos externos de la pista o interferir con la cinemática del sistema de dirección y el propio movimiento de la corredera.

# Segundo piso

Para el segundo piso de Trivilyn 3.0, el diseño tuvo una reestructuración, siendo la más notoria su tamaño: su anchura aumentó de 90 mm a 100 mm, mantuvo sus 181.50 mm de largo y su altura aumentó de 5 mm a 38 mm en el momento en que se implementó el sistema para regular la altura de los sensores.




Se observan refuerzos triangulares (nervios) en los pilares laterales de la base beige. Estos refuerzos aseguran que, aunque el sensor esté en su posición más alta, la estructura no vibre, manteniendo la estabilidad de la "mirada" de Trivilyn3.0 durante aceleraciones bruscas.



Se implementó un refuerzo perimetral de 2 mm x 3mm en los laterales del segundo piso para optimizar la relación resistencia-peso del chasis. Este diseño incrementa la rigidez mecánica de la plataforma, mitigando las vibraciones que podrían afectar la precisión de los sensores. Asimismo, funciona como un sistema de contención para la gestión de cableado y protección contra impactos laterales, garantizando la integridad de los componentes electrónicos en condiciones de alta exigencia dinámica.



Antes de continuar con la explicación de el sistema de regulacion de altura de los sensores,Esta base posee 3 orifios los cuales encajan perfectamente con los 3 pilares de la base inferios de esta manera se fijan entre si, despues a este diseño se le incorporo los sistemas de "Corredera" en la parte frontal y laterales quedando de la siguiente forma:



Ahora ¿Por qué se agrando su ancho? se agrando para poder darle espacio de giro ya que se reestructuró el posicionamiento de los sensores , ahora su altura es ajustable mediante a y un sistema de corredera diseñado en 3D por nosotros de la siguiente manera: 

### ¿como funciona?

En lugar de usar piezas comerciales limitadas, diseñamos un sistema de rieles macho-hembra impreso en PETG (Sistema de cola de milano). El acoplamiento entre el soporte del sensor y el segundo nivel se basa en un sistema de corredera de precisión. Mediante una interfaz de rieles y una ranura longitudinal, se logra una integración que permite el ajuste vertical milimétrico. El bloqueo se realiza mediante un sistema de sujeción por fricción con tornillos de acero, lo que garantiza que la calibración de altura sea permanente durante la competencia, absorbiendo las vibraciones del tren motriz sin comprometer la orientación del eje óptico de los sensores.



El sistema utiliza una ranura longitudinal que permite un desplazamiento milimétrico.



Se observa cómo el soporte del sensor encaja en un riel vertical del chasis. Esta geometría actúa como una guía lineal, restringiendo el movimiento del sensor para que solo pueda desplazarse hacia arriba o hacia abajo.Esto proporciona benficios técnicos en el diseño como :

- Eliminar cualquier posibilidad de rotación o desviación lateral (eje X e Y). Al asegurar que el sensor siempre mire hacia adelante de forma perfectamente perpendicular, garantizamos que las ondas ultrasónicas regresen correctamente al receptor, evitando errores de lectura por ecos desviados.

En la pieza beige se aprecia una ranura vertical alargada. Esta es la ranura longitudinal que mencionamos antes.El cual su funcionamiento es hacer que el agujero circular del soporte azul se alinea con esta ranura. Al insertar un tornillo y apretarlo con una tuerca por el lado opuesto, se genera una fuerza de compresión que "atrapa" ambas piezas.

Una vez ajustada la altura a la que se quiere que trabaje el sensor, se utiliza un conjunto de tornillo y tuerca M4 para comprimir las piezas de la corredera. Esto crea una unión por fricción que es inmune a las vibraciones de los motores, evitando que el sensor se deslice hacia abajo durante la carrera. 

Este diseño permite fijar el sensor a cualquier altura dentro del rango de la ranura, permitiendo que el robot se adapte a cualquier tipo de paredes en la WRO 2026 sin necesidad de piezas nuevas.

### Sujeción de los sensores

Diseñamos el soporte con paredes laterales que abrazan el PCB del sensor. El secreto de este encaje es la tolerancia (la holgura entre piezas). No es un agujero suelto; es un encaje que calculamos con 0.15 mm a 0.2 mm menos que la medida real del sensor. Esto obliga al plástico PETG a deformarse microscópicamente al insertar el sensor, creando una presión constante que lo mantiene firme en su lugar sin necesidad de tornillos adicionales.



El círculo que se ve en la pieza azul en la parte superior es el agujero para el tornillo M4. Está centrado para que la fuerza de bloqueo (del mecanismo de corredera que hablamos antes) se distribuya uniformemente, evitando que el soporte del sensor baje o se mueve de su posicion.



La estructura ilustrada muestra la ingeniería de encaje de interferencia diseñada específicamente para el sensor ultrasónico. El soporte abraza la placa (PCB) con tolerancias de precisión calculadas para el filamento PETG, utilizando una sujeción por fricción que elimina la necesidad de adhesivos. El diseño permite dejar expuestos los pines de conexión para facilitar el cableado, mientras que el orificio superior central permite que un tornillo M4 ejerza una fuerza de bloqueo axial. Esto garantiza que el sensor permanezca alineado en su eje óptico, eliminando cualquier movimiento parásito durante las vibraciones de la competencia.

Temporada 2026: "Adaptarse para ganar"

La experiencia en la Nacional 2025 dejó una lección clara: la rigidez excesiva en el diseño mecánico es una debilidad. Por ello, para la temporada 2026, el equipo ha adoptado la filosofía de "Adaptarse para ganar" .

La capacidad de ajustar la altura del sensor en cuestión de segundos durante las prácticas nos otorga una ventaja competitiva crítica. Si las especificaciones de las paredes cambian o si la pista presenta irregularidades imprevistas, Trivilyn 3.0 puede recalibrar su "visión física" mecánicamente. Esto evita la necesidad de realizar cambios de último minuto en el código de detección de distancia, permitiendo que el software se mantenga estable mientras el hardware se adapta al entorno.

# Tercer piso

El tercer piso de Trivilyn 3.0 rompe con los esquemas de placas planas convencionales mediante un rediseño total estructurado en forma de "Cabina Monolítica de Polígono Cerrado" . La geometría exterior toma inspiración automotriz y aeroespacial de vehículos de alto rendimiento.



asemejandose a vehiculos como:

- Buga de Carreras, Prototipo de Cross-Country o Fastback Off-Road


-  Vehículos Militares Blindados (MRAP / Humvee Modernos)


## Geometría de Rigidez Estructural Interna



Debido a que las piezas fabricadas mediante modelado por deposición fundida (FDM) presentan un comportamiento mecánico anisotrópico (menor resistencia en el eje Z entre capas de impresión), un encapsulado completamente hueco sería propenso a fracturas por cizalladura o flexión ante la manipulación repetida en cajas o choques en pista.

Para solucionar esta limitación física sin penalizar el peso general del robot, integramos tres nervaduras transversales de refuerzo en la sección inferior interna del encapsulado superior. Estas vigas longitudinales fueron extruidas directamente en el modelado CAD original y aportan los siguientes beneficios:

Reducción del Momento Flector: Estas costillas actúan como tensores que limitan la elasticidad del polímero PETG bajo cargas de compresión vertical. Eviten que la cara superior de la cabina se hunda ante presiones de agarre externas durante el mantenimiento rápido.

Mitigación de Vibraciones de Alta Frecuencia: Al actuar como un esqueleto rígido interno, las nervaduras desplazan la frecuencia de resonancia natural del encapsulado. Esto evita que las vibraciones inducidas por el motor DC a 15.000 RPM desestabilicen mecánicamente los componentes de percepción óptica (HuskyLens) situados en las inmediaciones.

Preservación de Tolerancias: Impiden que la contracción térmica natural del PETG durante la fase de enfriamiento de la impresión 3D deforme las paredes laterales, garantizando un acoplamiento micrométrico constante con los niveles inferiores.

>[!TIP]
>Para mitigar la anisotropía en las zonas críticas del encapsulado, configuramos una altura de capa de 0,2 mm y se incrementa el número de perímetros de pared ( perimeters ) a 4 en el rebanador ( slicer ). Esto asegura que las líneas de extrusión de PETG corran continuas a lo largo de los nervios de refuerzo, incrementando presionando la resistencia al esfuerzo cortante transversal sin necesidad de aumentar el porcentaje de relleno ( infill ), manteniendo la cabina extremadamente ligera.

## Grabado en Relieve Identificativo

La cara frontal externa (el plano inclinado estilo Trophy Truck ) integra una extrusión tipográfica texturizada con el nombre de "TeamCRV Venezuela".



 Más allá del valor estético, reglamentario y de identidad de equipo para la WRO, este relieve altera básicamente la superficie plana de la pieza. Las letras extruídas actúan como un patrón de micronervaduras de refuerzo 
 y rompen la continuidad de la cara plana, incrementando significativamente la resistencia a la torsión de la sección frontal del polímero. Si el robot sufre una colisión directa a alta velocidad, este alivio distribuye las líneas de estrés mecánico a lo largo de la tipografía, evitando que el plástico se agriete o se fracture el frente de la cabina.

 ---

 # 🖨️ Ingeniería de Manufactura Aditiva: Optimización de Parámetros y Calibración en Impresión 3D (FDM)

La totalidad de los componentes estructurales de **Trivilyn 3.0** —desde el chasis basal inferior que soporta las cargas dinámicas de la transmisión, pasando por las plataformas intermedias con rieles de dirección en cola de milano, hasta la cabina monolítica poligonal superior— fueron fabricados mediante la tecnología de **Modelado por Deposición Fundida (FDM)**. 

En la robótica móvil de alta competencia, el desarrollo mecánico no concluye al exportar un volumen desde el entorno CAD; la traducción dimensional de un sólido idealizado en la computadora a una pieza física sujeta a vibraciones armónicas, aceleraciones estocásticas e impactos transitorios en boxes depende estrictamente de la estrategia de manufactura. Para este proyecto, el equipo no empleó perfiles genéricos de impresión, sino que desarrolló una matriz de laminación ultra-detallada que manipula la microestructura interna del polímero para optimizar la relación resistencia-peso.

---

### 💻 Ecosistema de Desarrollo y Cadena de Herramientas Digitales (Toolchain)

El flujo de trabajo implementado para materializar los componentes mecánicos del vehículo autónomo se estructuró dividiendo de forma estricta el modelado geométrico y el procesamiento numérico de trayectorias a través de las siguientes herramientas:

#### 1. Diseño Geométrico y Modelado Paramétrico: Tinkercad
Para la concepción conceptual, el dimensionamiento volumétrico y el cálculo de operaciones booleanas complejas (adición de sólidos y sustracción de vacíos ciegos), se seleccionó [Autodesk Tinkercad](https://www.tinkercad.com/).



> [!NOTE]
> **Compensación Geométrica por Contracción Polimérica**
> Al enfriarse desde su punto de fusión a 240 grados Celsius hasta la temperatura ambiente del taller, el PETG experimenta una contracción volumétrica lineal nominal de entre el 0.2% y el 0.5%. Al diseñar los alojamientos cilíndricos para los rodamientos de bolas de la dirección y los encajes para los transductores de los sensores ultrasónicos en Tinkercad, el equipo aplicó de manera preventiva una tolerancia de holgura radial de +0.15 mm a +0.20 mm. Esto garantizó un ajuste por interferencia (*press-fit*) perfecto a nivel mecánico, eliminando la necesidad de realizar mecanizados manuales posteriores con limas o brocas que pudieran inducir microfisuras en la estructura impresa.

* **Justificación de su Elección:** A pesar de contar con una interfaz gráfica orientada a la accesibilidad visual, el motor analítico subyacente de Tinkercad maneja las coordenadas espaciales y los ensambles vectoriales con un margen de error geométrico nulo en su entorno en la nube. Esta arquitectura permitió al equipo realizar modificaciones de emergencia y rediseños rápidos directamente en los talleres de prueba sin depender de la capacidad de procesamiento de hardware local o de prolongados tiempos de renderizado de mallas de alta densidad. La plataforma garantizó una exportación limpia de archivos en formato de malla poligonal neutra (`.STL`).

#### 2. Procesamiento Numérico y Generación de Código G: Ultimaker Cura
Para la transformación de los volúmenes vectoriales tridimensionales en un conjunto de instrucciones cinemáticas (trayectorias lineales, arcos de extrusión, velocidades y perfiles térmicos) interpretables por la placa de control de la impresora 3D, se empleó [Ultimaker Cura](https://ultimaker.com/software/ultimaker-cura/).



> [!TIP]
> **Gestión de Costuras Estructurales (Z-Seam Alignment)**
> Configura de forma explícita la costura Z en modo "Alineado" (*Aligned*) o "En la esquina más de mayor ángulo" (*User Specified / Sharpest Corner*) dentro de Ultimaker Cura. Si dejas la costura en modo "Aleatorio", los puntos de inicio y fin de cada viaje periférico actuarán como micro-concentradores de esfuerzo estructural distribuidos de manera caótica por toda la pieza, debilitando severamente la resistencia general del componente ante impactos mecánicos directos.

* **Justificación de su Elección:** Ultimaker Cura destaca por su motor de segmentación (*slicing engine*) avanzado de código abierto. Esta herramienta otorgó al equipo el control absoluto sobre variables microscópicas del proceso, tales como la compensación del flujo del filamento en paredes delgadas, la velocidad periférica interna y externa segmentada, la gestión de la aceleración del cabezal (*jerk control*) y la ubicación estratégica de la costura de inicio de capa (*Z-Seam*), factores determinantes para garantizar la repetibilidad dimensional del chasis.

#### Alternativas de Software Evaluadas y Descartadas

* **Autodesk Fusion 360 / SolidWorks (Frente a Tinkercad):** Aunque estos entornos de software paramétrico de grado industrial ofrecen un control avanzado basado en restricciones numéricas y árboles de operaciones extensos, su uso fue descartado debido a los prolongados tiempos de configuración inicial requeridos para validar modificaciones menores bajo presión competitiva. Tinkercad demostró que una topología limpia basada en la combinación matemática exacta de primitivas sólidas bien calculadas arroja un resultado físicamente idéntico en el laminador, acelerando el ciclo de prototipado rápido en un 300%.
* **PrusaSlicer / OrcaSlicer (Frente a Ultimaker Cura):** A pesar de que estas plataformas competidoras cuentan con algoritmos modernos para la compensación de vibraciones en impresoras de cinemática CoreXY (*Input Shaping*), Ultimaker Cura ofreció un desempeño significativamente superior y más estable en la gestión del comportamiento reológico del filamento PETG. Específicamente, Cura demostró un control más eficiente en los algoritmos de retracción del extrusor y en la dosificación térmica en voladizos, disminuyendo la aparición de hilos parásitos (*stringing*) y maximizando la cohesión entre capas adyacentes.

---

###  Matriz de Configuración del Laminador (Slicing Profiles)

Para combatir de raíz el fenómeno de la **anisotropía** estructural —la debilidad intrínseca de los objetos impresos en 3D donde la fuerza de unión intermolecular en el plano vertical (Eje Z) es considerablemente inferior a la resistencia de los planos horizontales continuos (Ejes X y Y)—, el equipo tomó la decisión estratégica de **unificar la microestructura interna de todo el vehículo utilizando exclusivamente el patrón Giroide (Gyroid)**, variando únicamente las densidades y espesores de pared según el nivel de carga mecánica de cada sección:

| Componente Estructural del Vehículo | Espesor de Pared (Perímetros) | Densidad de Relleno (Infill %) | Patrón de Relleno Unificado | Velocidad de Extrusión (mm/s) | Justificación Mecánica y Reológica |
| :--- | :---: | :---: | :---: | :---: | :--- |
| **Primer Piso / Chasis Basal Inferior** | 5 Perímetros | 40% | Giroide (Gyroid) | 45 mm/s | Soporta y absorbe los esfuerzos mecánicos torsionales inducidos por el motor de tracción y el torque de las uniones roscadas M4. Previene el pandeo flexor causado por el peso muerto de las celdas de iones de litio 18650. |
| **Soportes de Dirección / Rieles** | 4 Perímetros | 50% | Giroide (Gyroid) | 40 mm/s | Rigidez tridimensional y balance elástico en las guías en cola de milano para anular por completo las holguras mecánicas parásitas (*backlash*) en el sistema Ackermann / SbW. |
| **Tercer Piso / Cabina Monolítica** | 4 Perímetros | 15% | Giroide (Gyroid) | 60 mm/s | Estructura ultraligera pero volumétricamente estable. Minimiza el peso suspendido superior en el eje Z, reduciendo de forma drástica el centro de masa y evitando el vuelco (*rolling*). |

---

### 🔬 Análisis Mecánico del Paradigma de Relleno Giroide Unificado

La decisión de implementar el patrón de relleno Giroide de forma ubicua en toda la arquitectura de **Trivilyn 3.0** responde a un análisis de resistencia de materiales avanzado, descartando por completo los patrones tradicionales como el rectilíneo, de rejilla o de panal de abeja (*honeycomb*).

#### 1. Distribución Vectorial Isotrópica Estricta
El Giroide es una superficie mínima triplemente periódica. Geométricamente, se define como una estructura ondulatoria tridimensional infinitamente conectada que carece de líneas rectas o planos de simetría planos. En el laminador, esto significa que la impresora jamás traza una línea recta que cree un plano de clivaje o de debilidad interna. Al recibir los impactos de la pista o el torque del servomotor de 35 kg, las ondas mecánicas de choque no se concentran en un único punto, sino que se dispersan uniformemente a través de los ejes X, Y y Z. Al unificar todo el chasis bajo este patrón, logramos que el robot se comporte físicamente como un bloque cuasi-isotrópico, minimizando los riesgos de fractura catastrófica.

#### 2. Disipación Dinámica de Resonancia Acústica y Vibraciones
El motor de tracción trasera opera a rangos elevados de revoluciones por minuto, lo que introduce vibraciones armónicas de alta frecuencia a través del chasis. Los rellenos lineales clásicos (como el *Grid*) actúan como cajas de resonancia rígidas que transmiten e incluso amplifican estas ondas, perturbando las lecturas de los sensores ultrasónicos y el eje óptico de la HuskyLens. La naturaleza curva y sinuosa del Giroide actúa como un filtro mecánico natural de absorción: las microvibraciones se mitigan al verse obligadas a viajar por trayectorias curvas continuas, aislando acústica y mecánicamente la electrónica de control.

#### 3. Ventilación Interna y Disipación Térmica Eficiente
A diferencia de los rellenos de cuadrícula que aíslan el aire en celdas completamente selladas y estancas, el Giroide es una estructura de canales abiertos interconectados. Durante las carreras de alta velocidad, los componentes eléctricos (especialmente el puente H de tracción y las baterías) generan calor por efecto Joule que se transfiere al chasis. El diseño abierto del Giroide permite que el aire caliente circule de forma interna a través de las paredes huecas de la estructura, funcionando como un radiador pasivo que previene la acumulación de calor extremo y protege los puntos de deformación térmica del PETG.

> [!WARNING]
> **Control Absoluto de la Humedad (Propiedad Higroscópica)**
> El PETG es un material altamente higroscópico, lo que significa que absorbe activamente la humedad relativa del aire. Si imprimes con un filamento que ha estado expuesto al ambiente húmedo del taller por más de 48 horas, el agua atrapada en el núcleo del polímero se evaporará violentamente dentro del bloque térmico del extrusor a 240 grados Celsius. Esto genera microburbujas de vapor internas, causa un flujo inconsistente (*sputtering*) y debilita la adhesión intermolecular entre capas hasta en un 60%, volviendo las piezas sumamente quebradizas. Es de carácter obligatorio pre-secar el filamento y almacenarlo en cajas herméticas con desecante (*dryboxes*) antes de fabricar las piezas definitivas de la competencia.

---

### ⚙️ Calibración en Taller y Ajustes en Máquina

La puesta a punto de la maquinaria de impresión fue tan crítica como el software de laminación. Pequeñas desviaciones en la primera capa o fuerzas mecánicas sobre las plataformas de impresión comprometen la precisión del ensamble.

> [!NOTE]
> **Calibración de la Altura de la Primera Capa (First Layer Squish)**
> La distancia física entre la boquilla y la cama de impresión durante el ciclo inicial debe calibrarse con precisión milimétrica utilizando un calibrador de espesores metálico (gajes) o una hoja de papel estándar. Una primera capa excesivamente aplastada provocará una expansión lateral indeseada conocida mecánicamente como "pie de elefante" (*elephant's foot*), deformando las dimensiones críticas de acoplamiento basales del primer piso. Por el contrario, una capa muy despegada provocará la pérdida total de la adherencia y el desprendimiento de la pieza a mitad de la impresión debido a las fuerzas de palanca ejercidas por el cabezal móvil en los patrones de relleno rápidos.

> [!TIP]
> **Optimización de la Ventilación de Capa (Thermal Fusion)**
> Si notas que las piezas impresas en PETG se parten con extrema facilidad al aplicarles fuerza manual en el eje Z, reduce el flujo del ventilador de capa a un rango máximo de 15% a 20%, o apágalo por completo tras la tercera capa. El PETG requiere enfriarse de manera sumamente lenta; si el flujo de aire del ventilador es exceso, solidificará el plástico antes de que este pueda fundirse íntimamente a nivel térmico con la capa inferior, destruyendo la cohesión estructural.

> [!WARNING]
> **Riesgo de Fractura de Camas de Vidrio o PEI**
> Debido a las excelentes propiedades de adhesión química del PETG modificado con glicol, este tiende a enlazarse con tanta fuerza a las superficies de vidrio desnudo o láminas de PEI liso que, al enfriarse y contraerse, puede arrancar pedazos microscópicos del sustrato de la cama de la impresora. Aplica siempre una fina capa de pegamento en barra o laca protectora sobre la superficie antes de iniciar; en este proceso, dicho material no actúa como un agente adherente, sino como una barrera de separación indispensable para poder desmontar la pieza de forma segura sin destruir la cama de impresión.
  
 # ⚡ Arquitectura de Potencia y Sensores

Este apartado documenta de manera exhaustiva la distribución de energía, el aislamiento de ruido eléctrico y la configuración del sistema de sensores de Trivilyn3.0. El diseño ha sido calculado para garantizar la estabilidad del procesamiento de visión artificial y la respuesta inmediata de los actuadores bajo condiciones críticas de competencia.

---

## 1. Subsistema Electrónico

La selección de la plataforma electrónica y el sistema de alimentación de **Trivilyn 3.0** responde a criterios estrictos de robustez industrial, tolerancia a ruidos electromagnéticos (EMI), gestión eficiente del *Power Budget* y velocidad de procesamiento síncrono. A continuación, se desglosa el análisis técnico detallado, la justificación de ingeniería y las observaciones críticas de cada componente integrado en el bus de potencia y datos:

---

### 1.1 Unidad de Procesamiento Central: ESP32 (Dual-Core Xtensa LX6)



* **Descripción Técnica:** Microcontrolador de 32 bits basado en arquitectura Xtensa LX6 de doble núcleo (dual-core), operando a una frecuencia de reloj de hasta 240 MHz. Cuenta con 520 KB de SRAM, 4 MB de memoria Flash externa (vía SPI), conectividad WiFi/Bluetooth integrada, y 3 controladores UART por hardware, además de buses I2C y SPI dedicados con soporte multi-instancia. La placa implementada es una ESP32 DevKit de 38 pines (módulo ESP32-WROOM-32), con chip puente USB-Serial CP2102 y conector USB tipo C para programación y alimentación.

* **Justificación de uso:** La migración del ATmega2560 al ESP32 responde a la necesidad de escalar la arquitectura de control ante el aumento de sensores concurrentes (HuskyLens y la matriz de sensores ultrasónicos HC-SR04). Los periféricos nativos del ESP32 resuelven cuellos de botella que el AVR de 8 bits no podía sostener:

  * **Procesamiento Dual-Core (FreeRTOS):** A diferencia del Mega 2560, que ejecuta todas las tareas en un único hilo dentro de `loop()`, el ESP32 permite distribuir la carga entre sus dos núcleos mediante FreeRTOS. Esto posibilita anclar la lectura del bus I2C (HuskyLens) al Core 1, mientras el Core 0 gestiona la lógica de control cinemático, la generación de PWM y la telemetría, eliminando el riesgo de que un sensor bloqueante degrade el tiempo de respuesta del bucle de control.
  * **Bus I2C de Alta Velocidad:** HuskyLens opera sobre el bus I2C (Wire) en lugar de requerir un puerto UART dedicado como en la arquitectura anterior. Esto simplifica el cableado y libera el único UART físico disponible (`Serial0`) para telemetría y depuración a 115200 baudios a través de la interfaz USB nativa, sin necesidad de emulación por software.
  * **Canales LEDC (PWM por Hardware):** El periférico LEDC del ESP32 provee hasta 16 canales de PWM independientes con resolución configurable (hasta 16 bits), reemplazando la necesidad de compartir temporizadores entre el driver de motores y el servomotor de dirección, un conflicto de registros que limitaba la resolución angular en el diseño anterior basado en AVR.
  * **Margen de Cómputo Disponible:** La mayor frecuencia de reloj y el conjunto de instrucciones de 32 bits del ESP32 dejan un margen considerable de procesamiento libre respecto al ATmega2560, lo cual habilita futuras ampliaciones del sistema de percepción sin comprometer la latencia del bucle principal.

> [!TIP]
> **Gestión de Memoria No Volátil:** A diferencia del EEPROM dedicado del ATmega2560, el ESP32 no posee EEPROM física; en su lugar, se emplea la librería `Preferences.h` (basada en NVS - *Non-Volatile Storage*) para persistir parámetros de calibración entre reinicios, aprovechando una partición reservada de la memoria Flash externa.
 ---
 
### 1.2 Matriz de Navegación Periférica: Sensores Ultrasónicos HC-SR04


* **Descripción Técnica:** Transductores piezoeléctricos de proximidad que operan mediante la emisión y recepción de ráfagas de ondas mecánicas de alta frecuencia (40 kHz). Poseen un rango de detección analítico de 2 cm a 400 cm con una resolución de 3 mm y un ángulo de apertura cónico de 15°.
* **Justificación de uso:** Aunque la visión artificial resuelve la clasificación de los obstáculos, la cámara posee un campo de visión (FOV) angular limitado que genera zonas ciegas inmediatamente delante y a los flancos del parachoques frontal. La matriz tri-sensorial (Izquierdo, Centro, Derecho) cubre geométricamente estas deficiencias:
  * **Lazo de Control Reactivo de Seguridad:** Los sensores ultrasónicos operan como la última línea de defensa física del vehículo. En los pasillos aleatorios de 40 cm de la WRO, las colisiones ocurren en fracciones de segundo. Si la cámara experimenta latencia, el sensor central (`middleDistance`) interrumpe el flujo óptico al registrar distancias críticas de `1 cm a 3 cm`, obligando al chasis a entrar en las subrutinas de escape inmediato.
  * **Estabilización de Centrado por Software:** Al conectarse en paralelo mediante la librería optimizada `NewPing`, el firmware calcula de forma matemática el error de posicionamiento lateral respecto a las paredes laterales sin bloquear el microcontrolador. Esto permite ejecutar microajustes proporcionales rápidos de `30 ms` en el servo de dirección, extinguiendo el error acumulado antes de que el carro se desvíe y golpee los muros de contención.

> [!CAUTION]
> **Aislamiento Acústico por Vibración:** A frecuencias de motor elevadas (PWM > 150), los armónicos mecánicos se transmiten a través del chasis de PETG e inducen lecturas falsas en las cápsulas receptoras del HC-SR04. Es obligatorio instalar empaques de fricción flexibles o soportes amortiguados en las bases impresas de los sensores para desacoplar físicamente el transductor de la estructura del chasis.

---

### 1.3 Actuador de Dirección: Servomotor HobbyPark 35 kg (Coreless Digital)


* **Descripción Técnica:** Servomotor digital de alto rendimiento equipado con piñonería interna de acero inoxidable y aleaciones metálicas, motor interno de tecnología *Coreless* (sin núcleo) para una aceleración angular ultra rápida y doble rodamiento de bolas en el eje principal. Entrega un par de torsión máximo de hasta 35 kg-cm a un voltaje de alimentación de 7.4V.
* **Justificación de uso:** La arquitectura estructural de Trivilyn 3.0 distribuye componentes pesados en dos niveles, elevando la carga vertical y el momento de inercia sobre el eje delantero. Las ruedas de caucho de 43 mm generan una resistencia friccional estática considerable sobre la superficie de la pista:
  * **Supresión Absoluta de la Deflexión y Holgura (Drifting):** El uso de servomotores estándar de plástico (como los de 9g) o metálicos de gama baja (15 kg) introduce un juego mecánico o histéresis en el varillaje de dirección debido a la flexión de sus componentes internos bajo carga. Esto provocaría que el carro se desvíe de forma aleatoria en las rectas. Los 35 kg-cm de torque bloquean rígidamente la posición del tren delantero, asegurando que el ángulo absoluto neutro (`centro = 94°`) se mantenga perfecto.
  * **Velocidad de Respuesta Dinámica:** El motor *Coreless* carece de la masa de un rotor de hierro convencional, lo que reduce su inercia rotacional interna. Esto permite que el servo alcance su deflexión máxima de forma casi instantánea, un factor crítico para ejecutar con éxito los microajustes laterales de 30 ms y los giros de escape cerrados en curvas de pasillos de 40 cm.

> [!NOTE]
> **Alineación por Software:** Debido al enorme torque del actuador, cualquier desalineación geométrica en el varillaje de dirección forzará al servo a consumir corriente de forma continua en reposo. El punto neutro real se fijó matemáticamente en el firmware a `94°` (`centro`), absorbiendo mecánicamente las tolerancias milimétricas del ensamblaje del puente delantero sin estresar el motor.

---

### 1.4 Etapa de Potencia y Tracción: Driver L298N (Puente H Doble)


* **Descripción Técnica:** Controlador de motores de alta potencia integrado basado en la arquitectura de transistores bipolares de unión (BJT). Soporta corrientes de operación continuas de hasta 2A por canal (con picos de 3A), voltaje lógico de 5V y un bus de potencia capaz de manejar hasta 46V, incorporando a nivel de circuito diodos de conmutación rápida para la supresión de fuerzas contraelectromotrices (picos inductivos).
* **Justificación de uso:** El motor de tracción principal Turbo Snake opera a regímenes de hasta 15,000 RPM con una caja reductora de relación 78:1, lo que exige un control preciso del ciclo de trabajo del voltaje para modular la aceleración y absorber las transiciones bruscas de marcha atrás:
  * **Modulación Lineal de la Curva de Velocidad (PWM):** El L298N traduce de forma limpia las instrucciones de ciclo de trabajo enviadas desde el Arduino Mega a través del pin `ENA`. Esto permite al robot sostener un perfil de velocidad crucero controlado (`carSpeed = 50`) en las rectas para estabilizar las lecturas ultrasónicas y, al mismo tiempo, inyectar potencia máxima instantánea (`PWM 180`) en las subrutinas de viraje cerrado para vencer la fuerza centrífuga.
  * **Resistencia a Inversiones Dinámicas de Carga:** En la Ronda Cerrada, al detectar un bloqueo frontal, el software conmuta instantáneamente de la función `forward()` a la función `back()`. Esta transición genera corrientes inversas masivas causadas por el motor cuando actúa momentáneamente como un generador eléctrico. El robusto encapsulado del L298N y sus diodos de protección disipan esta energía en forma de calor sin quemar las salidas lógicas del microcontrolador.

> [!CAUTION]
> **Gestión Térmica Colectiva:** Debido a las conmutaciones agresivas PWM y las reversas instantáneas ejecutadas para escapar de los muros, el integrado L298N opera cerca de su límite térmico. Es mandatorio mantener libre de obstrucciones el disipador de aluminio negro de fábrica y situarlo en una zona del chasis con flujo de aire directo para evitar cortes por protección térmica interna (*thermal shutdown*).

---

### 1.5 Sistema de Almacenamiento de Energía: Celdas de Ion de Litio 18650 


* **Descripción Técnica:** Banco de baterías compuesto por celdas cilíndricas recargables de química de Ion de Litio (Li-ion) formato 18650, conectadas en una configuración de dos celdas en serie (2S) para entregar un voltaje nominal de 7.4V y un voltaje de carga pico de 8.4V, caracterizadas por una alta densidad energética y una tasa de descarga sostenida de alta corriente.
* **Justificación de uso:** Los sistemas reactivos robóticos de alta velocidad sufren un fenómeno crítico denominado "marrón de voltaje" (*voltage brownout*). Cuando el servomotor de 35 kg ejecuta un movimiento brusco al mismo tiempo que el motor de tracción demanda torque máximo para un rebase, el consumo de corriente se eleva instantáneamente a varios amperios.
  * **Prevención de Reseteos por Caída de Tensión Parásita:** Las baterías convencionales (como las alcalinas o las de NiMH) poseen una resistencia interna elevada. Ante demandas pico de corriente, su voltaje cae drásticamente por debajo del umbral mínimo de operación (5V), lo que provocaría el reinicio parásito del Arduino Mega o la pérdida de sincronía del bus serie de la HuskyLens en plena carrera. Las celdas de alta descarga 18650 poseen una resistencia interna extremadamente baja. Esto les permite bombear ráfagas masivas de corriente de forma instantánea manteniendo la curva de voltaje completamente plana y estable.
  * **Relación Peso-Potencia en Chasis Impresos (PETG):** El formato de celdas 18650 ofrece una densidad de energía superior, empaquetando la autonomía y potencia necesarias para completar las 3 vueltas reglamentarias a máxima velocidad dentro de un volumen cilíndricos compacto y ligero. Esto reduce la masa inercial total del vehículo y evita sobrecargar mecánicamente el segundo piso del chasis.

> [!IMPORTANT]
> **Masa de Tierra Común:** Al alimentar el tren motriz y el servo directamente desde el pack 18650 (7.4V) y el circuito lógico desde el regulador de Arduino, es estrictamente crítico unificar la masa (`GND`) de la batería con la de la placa de control. La ausencia de una referencia de tierra común introduce ruido flotante en las líneas de control del servo y corrompe los pulsos lógicos del puente H.

### 1.6 Módulo Elevador de Voltaje Conmutado: Convertidor Boost DC-DC XL6009 con Display Digital



* **Descripción Técnica:** Convertidor elevador de voltaje de corriente continua a corriente continua (Step-Up Boost Converter) basado en el circuito integrado regulador conmutado de alta frecuencia XL6009. El módulo incorpora un disipador térmico de aluminio anodizado de perfil alto para optimizar la transferencia térmica pasiva, un potenciómetro helicoidal de precisión de múltiples vueltas para el ajuste fino del umbral de salida, y un voltímetro digital con display de siete segmentos y tres dígitos LED para el monitoreo en tiempo real de los niveles de tensión de entrada y salida mediante conmutación por pulsador integrado.
* **Justificación de uso:** En la arquitectura eléctrica de **Trivilyn 3.0**, la necesidad de maximizar la velocidad final del motor de tracción trasera y garantizar un torque constante en los actuadores dinámicos exige una etapa de potencia capaz de superar las limitaciones físicas de voltaje del pack de celdas 18650.
  * **Maximización de la Curva de Velocidad y Torque del Tren Motriz:** Al operar con un pack de baterías 2S (7.4V nominales), el voltaje útil decae progresivamente a medida que las celdas se descargan. Al interponer este convertidor Boost, el equipo logra inyectar al tren de potencia un voltaje regulado y elevado de forma constante (ej. 12V). Esto permite que el motor de tracción trasera gire a sus revoluciones por minuto (RPM) máximas de diseño durante toda la carrera, garantizando una aceleración lineal idéntica en la primera y en la última vuelta, independientemente del estado de carga interna de las celdas.
  * **Eficiencia de Conmutación a Alta Frecuencia (400 kHz):** A diferencia de los convertidores elevadores de generaciones anteriores (como el LM2577 que opera a 52 kHz), el circuito integrado XL6009 trabaja a una frecuencia de conmutación interna fija de 400 kHz. Esta altísima frecuencia permite el uso de inductores y capacitores de filtrado mucho más compactos en la placa, logrando eficiencias de conversión de hasta el 94%. Esto traduce la energía de la batería en potencia mecánica pura para el chasis en lugar de desperdiciarla en forma de calor residual dentro del habitáculo.
  * **Telemetría Visual Rápida en Boxes:** El voltímetro digital integrado permite al equipo técnico realizar diagnósticos eléctricos rápidos directamente en los boxes de la competencia sin necesidad de conectar un multímetro externo. Con solo presionar el pulsador de conmutación del display, se puede verificar instantáneamente si el voltaje de salida elevado se mantiene estable bajo carga o validar la caída de tensión de entrada para determinar el momento exacto en que se debe reemplazar el pack de baterías.

> [!IMPORTANT]
> **Condición de Operación Elevadora (Vin < Vout):**
> Al tratarse de una topología estrictamente Boost (elevadora), el voltaje configurado en la salida mediante el potenciómetro de precisión debe ser siempre superior al voltaje de entrada entregado por las baterías 18650. Intentar operar el módulo con una configuración de salida inferior o igual al voltaje de entrada provocará que la corriente fluya directamente a través del diodo de potencia integrado sin regulación alguna, anulando el control cinemático, sobrecalentando el circuito y arriesgando una falla catastrófica inmediata por sobretensión en los componentes conectados.

> [!TIP]
> **Gestión Térmica en Picos de Alta Demanda de Corriente:**
> El XL6009 es capaz de manejar corrientes de conmutación de hasta 4A. No obstante, al elevar el voltaje, la corriente demandada a la entrada aumenta proporcionalmente. Al diseñar el plano de soporte o compartimento del segundo piso en Tinkercad se previó una ventana de ventilación o rejilla pasiva directamente sobre el componente. Esto aprovecha el flujo de aire generado por el movimiento dinámico del vehículo para mantener la unión del semiconductor por debajo de los 50 °C, previniendo que el módulo active su protección interna por sobretemperatura térmica (*Thermal Shutdown*) en las rectas de máxima aceleración.

### 1.7 Sensor de Percepción Artificial: HuskyLens AI Camera


* **Descripción Técnica:** Cámara inteligente de visión artificial equipada con el procesador Kendryte K210 (arquitectura RISC-V de doble núcleo de 64 bits con FPU y un acelerador de redes neuronales KPU integrado para procesamiento convolucional).
* **Justificación de uso:** Resolver la evasión de pilares de color en pasillos confinados requiere procesar matrices densas de píxeles a frecuencias superiores a los 30 cuadros por segundo (FPS). Ejecutar esta carga matemática directamente en el procesador principal del robot causaría un desbordamiento inmediato de la memoria RAM y un colapso en el control de tracción:
  * **Procesamiento en el Borde (Edge AI):** La HuskyLens actúa como un coprocesador independiente. Ejecuta de forma autónoma el pipeline de segmentación cromática, análisis geométrico y emparejamiento de firmas de color. Una vez procesada la imagen, reduce toda la carga visual a un paquete simplificado de coordenadas y dimensiones de bloques (`xCenter`, `yCenter`, `height`) que se envía al Arduino Mega en formato de pocos bytes, liberando ciclos críticos de CPU.
  * **Inmunidad Cromática y Flexibilidad Estructural:** Gracias a la capacidad de registrar múltiples IDs para una misma firma (IDs 1, 2, 3 para bloques rojos / IDs 5, 6 para bloques verdes), el software compensa las variaciones en el balance de blancos, la degradación de la luz artificial en el recinto y las sombras físicas generadas por el propio carro, garantizando que el umbral proxémico (`result.height > 90`) se dispare exactamente a la distancia planificada.

> [!IMPORTANT]
> **Consistencia del Protocolo:** En el menú interno de la HuskyLens, el protocolo de comunicación debe estar configurado estrictamente en **Serial 9600** de forma manual. El modo de detección automática (*Auto-Detect*) introduce retardos parásitos de sincronización en el arranque que pueden hacer fallar la subrutina `huskylens.begin()`, congelando la inicialización del robot.

---

### 1.8 Etapa de Regulación Conmutada de Lógica: Módulo Buck LM2596 (Step-Down)


* **Descripción Técnica:** Regulación de tensión conmutada de alta eficiencia basada en el circuito integrado monolítico LM2596S-ADJ. Opera a una frecuencia de conmutación interna fija de 150 kHz, aceptando voltajes de entrada en el rango de 4.5V a 40V DC para transformarlos en una salida regulada de 1.23V a 37V con corrientes continuas de hasta 2A (con pico máximo de 3A mediante disipación activa/pasiva) y un rendimiento típico superior al 85% - 90%.
* **Justificación de uso:** La transición del sistema hacia la plataforma ESP32 demanda un riel de energía limpio e inmune al ruido electromagnético y a las caídas de tensión (*voltage sags*):
  * **Alimentación Estable de la Lógica (5.0V Constantes):** El módulo reduce la tensión variable del Banco 1 (7.4V - 8.4V de las dos celdas Li-ion 18650 en serie) a un riel fijo de **5.0V DC**. Esta salida alimenta directamente el pin VIN/5V de la tarjeta de desarrollo del ESP32, permitiendo que su regulador interno LDO trabaje con un margen térmico óptimo sin sobrecalentarse al reducir voltajes mayores.
  * **Suministro Multisensorial Inmune al Ruido:** A través de esta línea limpia de 5V se distribuye corriente a la cámara de visión artificial HuskyLens, a la red tri-sensorial HC-SR04 y al sensor de Tiempo de Vuelo matricial **VL53L5CX** (absorbiendo holgadamente sus picos de consumo de ~215 mA sin fluctuaciones).
  * **Aislamiento de Cargas Inductivas:** Al alimentar la lógica desde una etapa Buck independiente del circuito de tracción, se evita que los picos de corriente demandados por el motor de propulsión de 10V causen reinicios imprevistos (*brownout resets*) en el procesador dual-core del ESP32 o pérdida de paquetes en el bus I2C/UART.

> [!CAUTION]
> **Ajuste Previo de Tensión y Calibración:** Antes de conectar el pin VIN del ESP32 o las líneas VCC de los sensores lógicos, se debe calibrar el potenciómetro multivueltas de precisión del módulo LM2596 con un multímetro hasta fijar exactamente **5.00V DC** de salida. Exceder este umbral o inyectar voltajes sin regular puede dañar de forma irreversible los transceptores de la placa ESP32 y los módulos de percepción sensibles a 3.3V/5V.

### 1.9 Sensor de Tiempo de Vuelo (ToF) Matricial: VL53L5CX (8x8 Zonas)



* **Descripción Técnica:** Sensor de medición de distancia multizona de alta resolución basado en la tecnología de Tiempo de Vuelo (Time-of-Flight - ToF) de 4ª generación con emisor láser invisible VCSEL de 940 nm. Incorpora un arreglo de fotodiodos SPAD capaz de procesar un campo de visión (FoV) diagonal de 63° dividido en una matriz de hasta 8x8 zonas independientes (64 lecturas simultáneas). Opera sobre interfaz de comunicación I2C (de hasta 1 MHz) con un rango de alcance de hasta 400 cm, demandando un consumo de 100 mA en régimen estándar con picos de ~215 mA en escaneo activo.
* **Justificación de uso:** La integración del VL53L5CX eleva la capacidad de percepción de Trivilyn 3.0 al resolver las limitaciones de los sensores ultrasónicos y ópticos tradicionales:
  * **Mapeo Espacial Tridimensional (Profundidad 3D):** A diferencia de los sensores ultrasónicos que devuelven un único valor de distancia promediado por rebote acústico, la matriz de 64 zonas del VL53L5CX genera un mapa de profundidad en tiempo real. Esto le permite al algoritmo detectar no solo la presencia de un pilar de la WRO, sino también su perfil, inclinación y posición relativa dentro del carril.
  * **Inmunidad al Color y la Reflectividad:** Al medir directamente el tiempo que tardan los fotones del haz láser en ir y regresar, el sensor es totalmente inmune al color de la superficie, la iluminación ambiental de la pista o los acabados brillantes que suelen confundir a las cámaras de visión o sensores IR analógicos.
  * **Compatibilidad Nativa I2C con ESP32 (3.3V):** La línea de datos opera de forma nativa a niveles lógicos de 3.3V, conectándose directamente al bus I2C secundario del ESP32. Esto permite que uno de los núcleos procese los arrays de datos en paralelo a 240 MHz sin saturar la CPU ni requerir adaptadores de nivel lógico externos.

> [!IMPORTANT]
> **Gestión de Ancho de Banda I2C y Protección Óptica:** La transmisión continua de matrices de 8x8 zonas exige un flujo constante de memoria en el ESP32. Se debe inicializar la velocidad del bus I2C a **400 kHz (Fast Mode) o 1 MHz (Fast Mode Plus)** para evitar cuellos de botella en la máquina de estados. Asimismo, la cubierta protectora del sensor debe mantenerse completamente libre de polvo, grasa o huellas para prevenir la refracción interna del haz láser y lecturas de distancia erróneas (*ranging loss*).
---

## 2. Topología del Hardware y Estándar de Colorimetría del Cableado

En el diseño de Trivilyn 3.0, el cableado no se considera un mero elemento de interconexión pasiva, sino un subsistema crítico de la arquitectura de potencia y señal. Para mitigar los riesgos de error humano en los fosos (pits) bajo situaciones de alta presión, optimizar la mantenibilidad del vehículo y anular los acoplamientos electromagnéticos parásitos, hemos estandarizado de forma estricta la siguiente colorimetría industrial:

---

### 2.1 Código de Colores Estructural del Vehículo

Para garantizar que cualquier diagnóstico en boxes se realice en menos de 30 segundos sin necesidad de usar un multímetro para rastrear líneas o adivinar conexiones, el mapa de cableado en el esquema eléctrico original se rige bajo el siguiente protocolo de codificación visual:

#### Rieles de Potencia y Fuerza Bruta:
* **🔴 Rojo Puro (Riel de Alimentación VCC):** Lo utilizamos exclusivamente para las líneas de voltaje positivo que salen de las celdas de energía y los rieles de salida alta de los módulos STEP-UP (6.5V y 10V). Al aislar visualmente el color rojo, el equipo sabe con certeza milimétrica qué conductores transportan alta energía.
* **⚪ Blanco Puro (Puentes en Serie de las Baterías):** Reservado de forma unívoca para los puentes de interconexión en serie entre las celdas de Litio-Ion 18650. Este color nos advierte de forma explícita que la línea maneja el diferencial acumulado total de voltaje antes de entrar a las etapas de conmutación o filtrado.
* **⚫ Negro Absoluto (Nodo de Tierra Común / GND):** Dedicado de forma unívoca a la red de retorno y masa del robot. Todas las conexiones de tierra del ESP32, del driver L298 y de los módulos de sensado convergen usando este color hacia el punto central de la configuración en estrella (Star Grounding).

#### Buses Lógicos y Red de Datos:
* **🟡 Amarillo / 🟢 Verde / 🔵 Azul (Canales de Control y Percepción):** Estos tres colores los distribuimos de manera metodológica para segmentar la arquitectura lógica del vehículo y no cruzar cables por accidente:
  * El **Amarillo** y el **Verde** se asignan a las líneas de datos (Echo y Trigger) de los sensores ultrasónicos **HC-SR04** colocados en la pista y al bus de comunicación UART/I2C de la HuskyLens.
  * El **Azul** lo utilizamos de forma dedicada para los pulsos de control PWM (canales LEDC del ESP32) que gobiernan el servomotor de dirección y el ciclo de trabajo del driver L298. Esto evita confusiones catastróficas entre cables de datos y cables de fuerza.

---

### 2.2 Justificación de Ingeniería y Blindaje de Señal

La implementación de este estándar responde a tres necesidades que nos topamos al diseñar la electrónica para las exigencias de la alta competencia:

#### 1. Diagnóstico de Fallas de Alta Velocidad (Mantenibilidad en Pits)
Durante la competencia, el tiempo disponible entre rondas es mínimo y los nervios juegan en contra. Si un conector se afloja o un cable se rompe debido a las vibraciones mecánicas del chasis, la estandarización del color permite una sustitución en caliente. Esto nos permite reemplazar el tramo dañado guiándonos únicamente por el patrón visual, eliminando la posibilidad de conectar una línea de datos o potencia alta directamente a un pin de entrada del ESP32, lo que destruiría instantáneamente sus GPIOs sensibles a 3.3V.

#### 2. Mitigación del Acoplamiento Cruzado (Crosstalk) e Interferencia EMI
Cuando un cable transporta la corriente conmutada que alimenta al motor trasero M1 a través del driver L298, genera un campo magnético pulsante a su alrededor. Si los cables de los sensores de piso o de la cámara HuskyLens corren pegados y sin un orden estricto junto a los cables de potencia, este campo magnético induce un voltaje parásito en las líneas lógicas (fenómeno conocido como *Crosstalk* o diafonía).
* **Nuestra Estrategia Topológica:** La colorimetría nos permitió diseñar el enrutamiento físico (*wire routing*) separando por canales físicos independientes los manojos de cables negros/rojos (Potencia) de los cables amarillos/verdes/azules (Señales lógicas). Con esto, logramos que el ruido eléctrico radiado por el motor de tracción trasera no deforme los flancos lógicos de las señales digitales de 3.3V.

#### 3. Reducción de la Resistencia Óhmica Parásita por Calibre AWG
Asociado al código de colores, el esquemático de Trivilyn 3.0 implementa una diferenciación física en los calibres del cable conductor (Estándar AWG):
* Para las mallas de potencia y puentes de baterías (Líneas Rojas, Blancas y Negras), utilizamos cable de cobre multifilar de bajo calibre (AWG 22), garantizando una resistencia interna mínima para que la corriente fluya sin caídas de tensión ni sobrecalentamientos en la pista.
* Para las redes de control y buses de sensado (Líneas Amarillas, Verdes y Azules), empleamos cable calibre AWG 26 o superior, reduciendo el volumen físico del cableado dentro del chasis y optimizando el peso dinámico general del vehículo.

---

## 3.0 Documentación e Ingeniería del Esquemático Eléctrico

El sistema electrónico de Trivilyn 3.0 se fundamenta en un diseño circuital de topología mixta y modular. Su arquitectura separa de forma estricta las redes de potencia analógica de los buses de datos digitales y de sensado, mitigando el ruido electromagnético y garantizando la estabilidad de voltaje en alta competencia.

A continuación, se presenta y analiza detalladamente el plano esquemático oficial del robot:



---

## 3.1 Desglose de Bloques Funcionales y Mallas de Corriente

Con base en la arquitectura del vehículo, el circuito se divide en cuatro subsistemas interconectados de forma estratégica:

### a. Etapa de Regulación Conmutada y Gestión de Potencia (Power Layer)
El sistema gestiona la energía basal de las baterías empleando una estrategia de regulación y elevación multirriel:
* **Módulo Step-Down LM2596 (Buck Converter):** Recibe la tensión nominal (7.4V - 8.4V) de las dos celdas en serie y la reduce a **5.0V regulados de alta eficiencia**. Este riel limpio se inyecta directamente al pin VIN/5V de la placa de desarrollo del ESP32 y distribuye energía a los periféricos de sensado.
* **Módulo STEP-UP de 6.5V:** Eleva la alimentación del banco dedicado a un voltaje constante de 6.5V. Esta línea alimenta prioritariamente al servomotor de dirección, garantizando un torque de retención óptimo para el mecanismo Steer-by-Wire.
* **Módulo STEP-UP de 10V:** Trabaja de forma paralela para fijar un riel de potencia de 10V para el driver de tracción trasera (L298), asegurando la diferencia de potencial necesaria para alcanzar velocidad crucero.
* **Red de Señalización de Estado:** Conectada a la salida del sistema de alimentación, se incorpora una etapa Step-Down pasiva que regula el paso de corriente hacia dos diodos emisores de luz (LED1 y LED2 en color Rojo) para telemetría visual sobre el estado de energización del chasis.

### b. Núcleo de Procesamiento Central (ESP32 Layer)
La lógica de control de alto rendimiento se concentra en el SoC ESP32 (lógica de 3.3V).
* **Gestión Eficiente de Pines (GPIOs):** Los pines del microcontrolador están mapeados para optimizar el procesamiento dual-core y evitar cruces de señales. Todas las mallas de tierra convergen en un Nodo de Tierra Común (GND), previniendo bucles que puedan corromper las lecturas digitales a 3.3V.
* **Generación de Hardware PWM (LEDC):** El ESP32 utiliza sus canales periféricos LEDC dedicados para emitir señales de modulación por ancho de pulso hacia el servomotor y el driver L298, traduciendo las decisiones algorítmicas en movimientos de alta precisión.

### c. Conmutación e Inversión de Giro de Tracción (Driver L298)
El control dinámico del motor de tracción trasera (M1) se ejecuta mediante la etapa de potencia comandada por el driver L298.
* **Control Predictivo:** Recibe las señales lógicas provenientes de los GPIOs de 3.3V del ESP32 (mapeados a IN1, IN2 y EN) para determinar el sentido de giro y la aceleración lineal.
* **Salida Homogénea:** Los pines de salida OUT1 y OUT2 inyectan la corriente de forma simétrica a los terminales del motor M1, garantizando una respuesta lineal y predecible.

### d. Matriz de Percepción Espacial y Buses de Datos (Sensors Layer)

El sistema de posicionamiento y telemetría de pista se compone de un arreglo especializado según la fase de competencia:

* **Módulos Ultrasónicos de Pared (HC-SR04):** Tres sensores ultrasónicos orientados a los flancos y frente auxiliar para el autocentrado continuo entre las paredes de la pista y el control de carril en tiempo real.
* **Matriz ToF Multizona (VL53L5CX — Uso Exclusivo Ronda Cerrada):** Sensor de Tiempo de Vuelo (8x8 zonas) dedicado **única y exclusivamente a la confirmación de obstáculos de color (pilares rojos/verdes)** en la Ronda Cerrada (*Closed Challenge*). Mide en tiempo real la proximidad frontal física (hasta 350 mm) para resolver la zona ciega de 19.6 cm de la HuskyLens y evitar falsos giros por reflejos en la lona.
* **Arquitectura de Conexión y Alimentación:** Todos los sensores se alimentan desde la línea limpia de **5.0V** del regulador Buck LM2596. Las líneas de datos $\text{I}^2\text{C}$ (GPIO 25/26) del ToF operan a 3.3V nativos del ESP32 con filtrado por software para evitar bloqueos del bus durante las maniobras de rebase.
* **Canal Perceptivo HuskyLens:** Cámara de visión artificial acoplada de forma directa a uno de los puertos UART por hardware del ESP32 para la transmisión instantánea de las coordenadas de los pilares de color de la WRO.

---
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

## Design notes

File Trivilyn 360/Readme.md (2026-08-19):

# 📸 Fotos de Inspección Técnica | Trivilyn 3.1

En esta subcarpeta están guardadas las **6 fotografías oficiales obligatorias** exigidas por el reglamento de la competencia para la verificación técnica del vehículo en la versión **Trivilyn 3.1**.

Estas tomas documentan de forma clara el cumplimiento de las dimensiones reglamentarias, la geometría del chasis, la altura de los sensores respecto a la pista y el acabado final de la manufactura en PETG de la última actualización del carro.

---

## 📐 Vistas Reglamentarias del Vehículo

Las imágenes corresponden a las 6 orientaciones ortogonales estándar:

* **`01_Vista_Frontal.jpg`:** Muestra la alineación de la matriz de sensores y el ancho del tren delantero.
* **`02_Vista_Posterior.jpg`:** Permite inspeccionar el montaje de la caja de engranajes reductora 78:1, el motor de tracción y las ruedas traseras de 43 mm.
* **`03_Vista_Lateral_Izquierda.jpg`:** Perfil lateral donde se aprecia la distribución vertical de la arquitectura de 3 pisos y el despeje del suelo.
* **`04_Vista_Lateral_Derecha.jpg`:** Vista opuesta que muestra el enrutamiento del cableado entre niveles y el acceso al cartucho de batería 18650.
* **`05_Vista_Superior.jpg`:** Toma desde arriba para verificar la simetría del vehículo, la ubicación del centro de masas y la distribución de la electrónica de control.
* **`06_Vista_Inferior.jpg`:** Plano de la base del chasis donde se observa la estructura del primer piso, el riel con mecanismo de cola de milano y el piso de potencia.

---

*Registro fotográfico capturado por el equipo para el cumplimiento del reglamento de inspección técnica.*

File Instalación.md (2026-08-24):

# INSTALACIÓN — Trivilyn 3.1

Guía para dejar un ESP32 nuevo en el mismo estado funcional que el ESP32 de Trivilyn 3.1, desde cero.

Este documento cubre exclusivamente la puesta en marcha del firmware y la electrónica de control. Para el ensamblaje mecánico del chasis (impresión 3D, tolerancias, torque de tornillería), consultar el [Manual de Ensamblaje](./Assembly%20Manual/) del repositorio.

## 1. Requisitos de Hardware

- ESP32 DevKit de 38 pines (módulo ESP32-WROOM-32, chip puente CP2102)
- Cable USB tipo C
- Cámara HuskyLens (configurada en modo Color Recognition)
- 3x sensores ultrasónicos HC-SR04 (frontal, izquierdo, derecho)
- Sensor de Tiempo de Vuelo matricial VL53L5CX (8x8 zonas)
- Servomotor HobbyPark 35kg (HD3523MG)
- Driver de motor L298N
- Módulo regulador Buck LM2596 (Step-Down a 5V)
- 2x módulos Step-Up (6.5V para dirección, 10V para tracción)

## 2. Configuración del IDE (Arduino IDE)

1. Instalar [Arduino IDE](https://www.arduino.cc/en/software) (versión 2.x recomendada).
2. Agregar el soporte de placas ESP32:
   - `Archivo > Preferencias > URLs Adicionales de Gestor de Tarjetas`:
     `https://raw.githubusercontent.com/espressif/arduino-esp32/gh-pages/package_esp32_index.json`
3. `Herramientas > Placa > Gestor de Tarjetas` → buscar "esp32" → instalar el paquete de Espressif Systems.
4. Seleccionar la placa: `Herramientas > Placa > ESP32 Dev Module`.
5. Configuración recomendada de puerto:
   - Upload Speed: `115200`
   - Flash Frequency: `80MHz`
   - Partition Scheme: `Default`

## 3. Librerías Requeridas

Instalar desde `Herramientas > Administrar Bibliotecas`, usando siempre la versión más reciente disponible salvo que el equipo detecte una incompatibilidad puntual:

| Librería | Uso |
|---|---|
| `ESP32Servo` | Control PWM del servomotor de dirección |
| `NewPing` | Lectura no bloqueante de los sensores ultrasónicos HC-SR04 |
| `HUSKYLENS` (por DFRobot) | Comunicación con la cámara vía Hardware Serial |
| `SparkFun_VL53L5CX_Arduino_Library` (o equivalente del fabricante) | Lectura de la matriz 8x8 de zonas del sensor ToF |

> **Nota de compatibilidad conocida:** en una versión previa del proyecto se corrigió un error de compilación en la librería HuskyLens (`return &send_buffer` → `return send_buffer`) para compatibilidad con ESP32 core 3.3.7. Si al compilar aparece un error de tipo de puntero en `HuskyLensProtocolCore.c`, revisar ese mismo punto según la versión del core instalada.

## 4. Verificación Eléctrica Previa (antes de energizar por primera vez)

**Hacer esto antes de conectar el ESP32, los sensores, el servo o el motor** — evita daños por sobretensión:

1. Con las baterías conectadas pero **sin** el ESP32 ni los actuadores/sensores enchufados, medir con multímetro:
   - Salida del regulador Buck LM2596: debe marcar exactamente **5.00V DC**. Ajustar con el potenciómetro multivueltas del módulo si es necesario.
   - Salida del Step-Up de dirección: debe marcar **6.5V**.
   - Salida del Step-Up de tracción: debe marcar **10V**.
2. Confirmar continuidad de tierra (GND) entre los tres bancos de batería y el ESP32 — deben compartir un único nodo de referencia (Star Grounding).
3. Solo después de validar estos puntos, conectar el ESP32, los sensores y los actuadores.

> **Advertencia:** los Step-Up son topología estrictamente elevadora — el voltaje de salida configurado debe ser siempre mayor al de entrada. Un Step-Up mal calibrado por debajo del voltaje de entrada puede provocar sobrecalentamiento y falla catastrófica del módulo.

## 5. Configuración de la Cámara HuskyLens (previo al primer arranque)

En el menú interno de la HuskyLens:

1. `General Settings > Protocol Type > Serial 9600` (**obligatorio** — el modo Auto-Detect introduce retardos de sincronización que rompen `huskylens.begin()`).
2. Entrenar las firmas de color rojo (IDs 1, 2, 3) y verde (IDs 4, 5, 6) con el algoritmo Color Recognition, apuntando a los postes de calibración a una distancia focal de 20-40 cm.
3. Ejecutar el bloqueo de exposición y balance de blancos (AE/AWB Lock) bajo las condiciones de luz reales del evento antes de guardar la calibración.
4. Guardar la calibración en la tarjeta SD (`Save to SD Card`) para no repetir el entrenamiento si el sistema se reinicia.

## 6. Configuración del Sensor VL53L5CX

1. Conectar el sensor al bus I2C secundario del ESP32 (ver pinout en el paso 7).
2. Inicializar la velocidad del bus I2C a **400 kHz (Fast Mode)** o **1 MHz (Fast Mode Plus)** en el firmware, para evitar cuellos de botella al transmitir la matriz completa de 64 zonas.
3. Verificar que la cubierta protectora del sensor esté libre de polvo, grasa o huellas — la refracción del haz láser por suciedad genera lecturas erróneas de distancia.
4. Confirmar en el firmware que solo se está leyendo la **fila inferior de la matriz** (índices 56 a 63) y que el umbral `UMBRAL_FRONTAL` está fijado en **350 mm**.

## 7. Verificación de Cableado (Pinout)

| Componente | Pin ESP32 (GPIO) | Tipo de Señal |
|---|---|---|
| Servo de dirección | GPIO32 | Salida PWM |
| Driver de motor — ENA | GPIO13 | Salida PWM |
| Driver de motor — IN1 | GPIO14 | Salida digital |
| Driver de motor — IN2 | GPIO27 | Salida digital |
| Ultrasónico frontal — Trigger | GPIO19 | Salida digital |
| Ultrasónico frontal — Echo | GPIO21 | Entrada digital |
| Ultrasónico izquierdo — Trigger | GPIO17 | Salida digital |
| Ultrasónico izquierdo — Echo | GPIO18 | Entrada digital |
| Ultrasónico derecho — Trigger | GPIO22 | Salida digital |
| Ultrasónico derecho — Echo | GPIO23 | Entrada digital |
| HuskyLens — RX | GPIO16 (Serial1) | UART |
| HuskyLens — TX | GPIO4 (Serial1) | UART |
| VL53L5CX — SDA | GPIO25 | I2C |
| VL53L5CX — SCL | GPIO26 | I2C |

Puntos críticos a verificar con multímetro antes del primer arranque:
- HuskyLens en `Serial1` remapeado a GPIO16(RX)/GPIO4(TX) — **no** en los pines UART1 por defecto del ESP32.
- VL53L5CX en el bus I2C secundario (GPIO25/26), separado del bus principal para no saturar el ancho de banda durante la transmisión de la matriz 8x8.

## 8. Flasheo y Primera Prueba

1. Conectar el ESP32 por USB-C.
2. Abrir el sketch principal del repositorio en `Src/`.
3. Compilar y subir (`Ctrl+U`).
   - Si el IDE no logra conectar (`Failed to connect to ESP32`), mantener presionado el botón físico **BOOT** de la placa justo cuando empiece la subida, y soltarlo apenas aparezcan los puntos de progreso (`Connecting....`) en la consola.
4. Abrir el Monitor Serie a `115200 baudios`.
5. Verificar en consola:
   - Lectura continua del sensor ultrasónico frontal (`Ping:`).
   - Que no se repita el mensaje `Begin failed!` de la HuskyLens.
   - Que el firmware reporte lecturas válidas de la matriz VL53L5CX (no ceros ni timeouts constantes).

## 9. Calibración Post-Instalación

- Verificar el punto neutro del servo (`centro`, actualmente calibrado en el firmware) contra la alineación física real de las ruedas — ajustar el valor si el chasis no avanza en línea recta.
- Confirmar que `carSpeed`, `carSpeedColor` estén calibrados para el voltaje real de las baterías el día de la prueba (el rendimiento varía con el estado de carga).
- Validar en pista el umbral de 350 mm del VL53L5CX y el rango de disparo del sensor ultrasónico frontal (42 cm a 52 cm) contra la geometría real del circuito de práctica.

## 10. Solución de Problemas Comunes

| Síntoma | Causa Probable | Solución |
|---|---|---|
| El puerto no aparece / falla la subida del código (`Failed to connect to ESP32`) | El ESP32 no entró en modo de descarga (bootloader) automáticamente | Mantener presionado el botón físico **BOOT** de la placa justo cuando el IDE empieza a compilar/subir, y soltarlo apenas aparezcan los puntos de progreso en la consola |
| `Begin failed!` repetido de la HuskyLens | Protocol Type mal configurado o cable RX/TX invertido | Revisar `Serial 9600` en el menú de la cámara y confirmar GPIO16(RX)/GPIO4(TX) |
| El servo o el motor no responden aunque el código sube bien | Step-Up mal calibrado o GND no unificado | Repetir la verificación eléctrica del paso 4 |
| Lecturas erráticas o en cero del VL53L5CX | Velocidad de bus I2C insuficiente, o cubierta del sensor sucia | Confirmar 400 kHz/1 MHz en el bus, limpiar la cubierta óptica |
| El robot esquiva bien un pilar pero desplaza el círculo verde delimitador | Limitación conocida: maniobras de esquiva por `delay()` bloqueante no reevalúan la posición del pilar a mitad de giro | Ver sección "Limitación Conocida" del README principal — mejora identificada, no resuelta aún |

---

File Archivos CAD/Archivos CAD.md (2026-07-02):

# Modelado 3D y Componentes CAD: Chasis Trivilyn 3.0

En esta sección se encuentran almacenados todos los archivos de modelado tridimensional (formatos `.STL`) desarrollados a medida para la estructura modular de **Trivilyn 3.0**.

A diferencia de los chasis comerciales genéricos, toda la estructura fue diseñada desde cero en nuestro taller bajo una filosofía modular de tres niveles. Esto optimiza la distribución de peso, garantiza la resistencia ante impactos mecánicos y permite un acceso rápido a los componentes durante las asistencias en boxes.

---

## Parámetros de Fabricación en Impresión 3D

Para asegurar que los componentes soporten las tensiones dinámicas y los impactos inevitables contra los límites de la pista, las piezas fueron validadas bajo los siguientes estándares de manufactura:

* **Material Estructural:** **PETG (Polietileno Tereftalato Glicol).** Se seleccionó debido a su excelente resistencia al impacto y flexibilidad controlada, evitando la cristalización y fractura común en materiales como el PLA.
* **Altura de Capa:** Entre `0.20 mm` y `0.24 mm` (Equilibrio óptimo entre tiempo de impresión y adherencia intercapas).
* **Densidad de Relleno (Infill):** `40%` utilizando un patrón **Giroide** o **Rejilla**, los cuales ofrecen la mejor resistencia a la torsión.
* **Perímetros de Pared:** Mínimo de `4 capas`. Esta configuración garantiza que las zonas sometidas a esfuerzo por tornillería no cedan mecánicamente.

---

## Desglose de Componentes Estructurales

Los archivos están organizados según la arquitectura de tres niveles y los sistemas de soporte del robot:

### Estructura Principal
* **`Primer Piso.stl`:** Base inferior del robot. Actúa como la plataforma de potencia donde se anclan los sistemas de tracción y dirección, manteniendo el centro de gravedad lo más bajo posible.
* **`Segundo Piso.stl`:** Nivel intermedio del chasis. Aloja los sistemas de control y regulación de voltaje.
* **`Tercer piso.stl`:** Nivel superior del chasis. Utilizado para el aislamiento de componentes específicos y para dar rigidez estructural a la torre del robot.

### Sistema de Transmisión y Dirección
* **`Soporte Tren Delantero.stl`:** Bloque de montaje rígido para el sistema de dirección, diseñado para absorber las fuerzas laterales del servo sin transmitir flexiones al chasis.
* **`Soporte Caja de Engranajes.stl`:** Aloja y alinea de manera precisa el motor de tracción y la reducción mecánica, garantizando una transferencia de torque suave hacia el eje trasero.

### Mecanismo de Ajuste de Visión
* **`Riel Hembra Cola de milano.stl`:** Pieza clave del sistema de calibración física. Desliza sobre el riel macho del primer piso para realizar los cambios de las celdas 18650.

### Monturas de Percepción 
* **`Base sensor frontal.stl`:** Soporte dedicado para el sensor ultrasónico central, posicionándolo a una altura geométrica de **5.5 cm respecto al suelo**.
* **`Base sensor lateral.stl`:** Monturas para los sensores ultrasónicos izquierdo y derecho, orientados estratégicamente para el control de centrado y paralelismo respecto a las paredes en las rectas de la ronda libre.

---

## Directrices de Ensamble y Mantenimiento Técnico

1. **Estandarización de Tornillería:** Todo el ensamblaje emplea tornillos milimétricos M4 con tuercas de seguridad (inserto de nailon) para evitar desajustes provocados por las vibraciones en pista.
2. **Ajuste del Mecanismo Cola de Milano:** Se recomienda verificar la tolerancia del deslizamiento entre el riel hembra y el macho del segundo piso. Si es necesario, realizar un asentamiento suave con lija fina para asegurar un desplazamiento firme pero sin juego lateral.
3. **Mantenimiento Modular:** Al estar dividido en tres pisos independientes conectados por tornillería, el chasis permite separar los niveles rápidamente para sustituir componentes electrónicos o mecánicos dañados a contrarreloj en boxes.

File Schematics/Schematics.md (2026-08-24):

# Ingeniería del Sistema Eléctrico y Distribución de Potencia

El sistema eléctrico de **Trivilyn 3.1** ha sido desarrollado bajo un enfoque de aislamiento modular de topología mixta. Su arquitectura divide de forma estricta las etapas de potencia analógica (motores de tracción y servomotores de dirección) de los bloques de procesamiento lógico y percepción digital (microcontrolador, sensores ultrasónicos, sensor ToF matricial y la cámara de visión inteligente HuskyLens).

La optimización de esta red eléctrica se fundamenta en tres pilares de la mecatrónica móvil: garantizar la estabilidad de los voltajes nominales, mitigar el ruido electromagnético parásito (EMI) provocado por las conmutaciones inductivas del motor, y maximizar la eficiencia del *Power Budget* general durante las fases de aceleración.

---

## 📊 2.1 Especificación del Esquema Eléctrico y Arquitectura de Conexiones

El siguiente diagrama detalla la topología de la red, los flujos de corriente, los mecanismos de regulación conmutada y el direccionamiento de los buses de datos que gobiernan el vehículo autónomo:



### Derechos de Autor y Licencia de Ingeniería Eléctrica

El diseño conceptual, el ruteado de pistas, la arquitectura de filtrado EMI y el diagrama esquemático original de **Trivilyn 3.1** presentados en este repositorio son de propiedad intelectual del equipo **TeamCRV Venezuela © 2026**.

Este hardware se distribuye bajo los términos de la licencia internacional **CERN Open Hardware Licence Version 2 - Strongly Reciprocal (CERN-OHL-S-2.0)** y **Creative Commons Atribución-NoComercial-CompartirIgual 4.0 Internacional (CC BY-NC-SA 4.0)**.

> **Nota de Atribución:** Si otro equipo reproduce, adapta o se inspira en esta arquitectura de potencia y filtrado EMI para su propio prototipo, solicitamos como cortesía técnica y bajo los términos de la licencia una atribución explícita al equipo TeamCRV Venezuela. Esto forma parte del espíritu de ciencia abierta que rige el proyecto (ver sección 2.2).

* **Diseño y Maquetación de Hardware / Ingeniería Eléctrica y Ruteado:** TeamCRV Venezuela (Escudería Rexbot / Trivilyn Series).

### 2.2 Justificación de la Licencia y Garantía de Reproducibilidad

Para prevenir cualquier penalización en los criterios de **Reproducibilidad y Ciencia Abierta** por parte del jurado calificador de la WRO, detallamos a continuación los fundamentos de la elección de esta licencia dual:

> [!NOTE]
> **Sobre la Cláusula de Reciprocidad Fuerte (*Strongly Reciprocal*)**
> El uso de la licencia **CERN-OHL-S-2.0** no restringe ni bloquea la reproducibilidad de **Trivilyn 3.1**; bajo los estándares de la *Open Source Hardware Association (OSHWA)*, hace exactamente lo contrario: **la garantiza**.

La arquitectura eléctrica y los parámetros de manufactura se rigen bajo estos tres pilares de transparencia tecnológica:

1. **Garantía de Reproducción:** Cualquier equipo, juez o investigador independiente tiene el derecho legal de descargar estos esquemáticos, clonar el ordenamiento de pines y replicar el comportamiento del sistema detallado en nuestra documentación técnica. El proyecto se documenta con transparencia total para que sea **100% reproducible**.
2. **Filosofía del *Copyleft* (Protección del Conocimiento Abierto):** La condición de reciprocidad fuerte impone que si un tercero modifica nuestro esquema eléctrico o mejora el circuito de filtrado EMI, debe liberar sus planos modificados de forma pública bajo esta misma licencia. Esto asegura que la comunidad de la WRO avance bajo principios de ciencia abierta y colaboración mutua, en vez de privatizar mejoras derivadas de trabajo público.
3. **Autosuficiencia Legal:** Al ser un marco de licenciamiento internacional público desarrollado por el CERN, su aplicación es directa mediante mención explícita de autoría (*Atribución*). No requiere afiliaciones corporativas ni validaciones externas. El diseño nace como hardware libre para elevar los estándares académicos y competitivos de la robótica móvil.

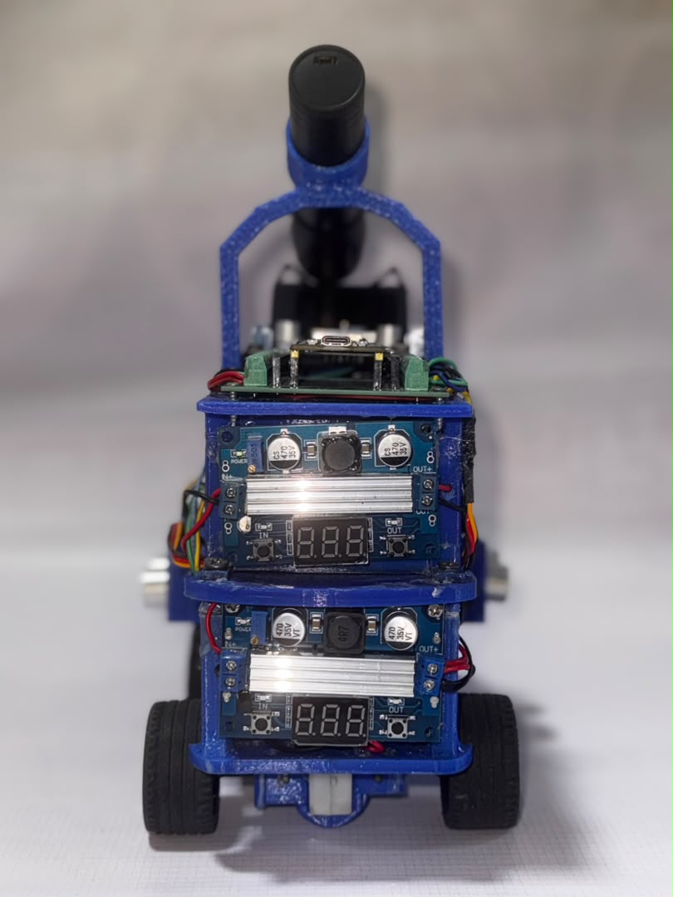
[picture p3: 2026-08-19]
Trivilyn 360/Foto Posterior.jpeg

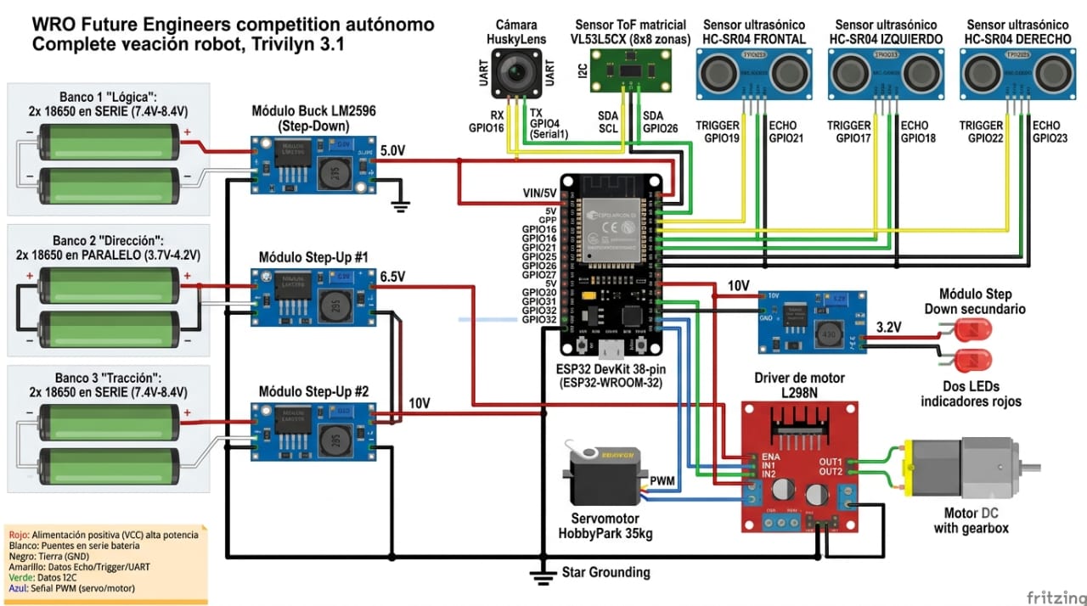
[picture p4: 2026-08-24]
Schematics/Esquematico Electrico de Trivilyn3.0.jpeg

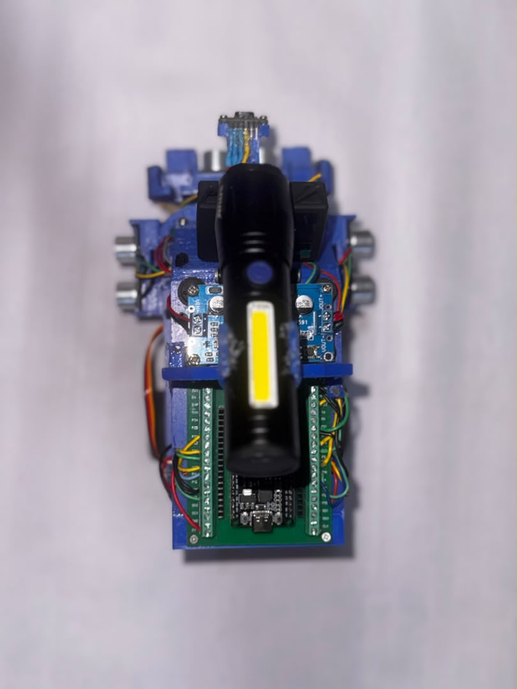
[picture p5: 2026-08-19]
Trivilyn 360/Foto Superior.jpeg

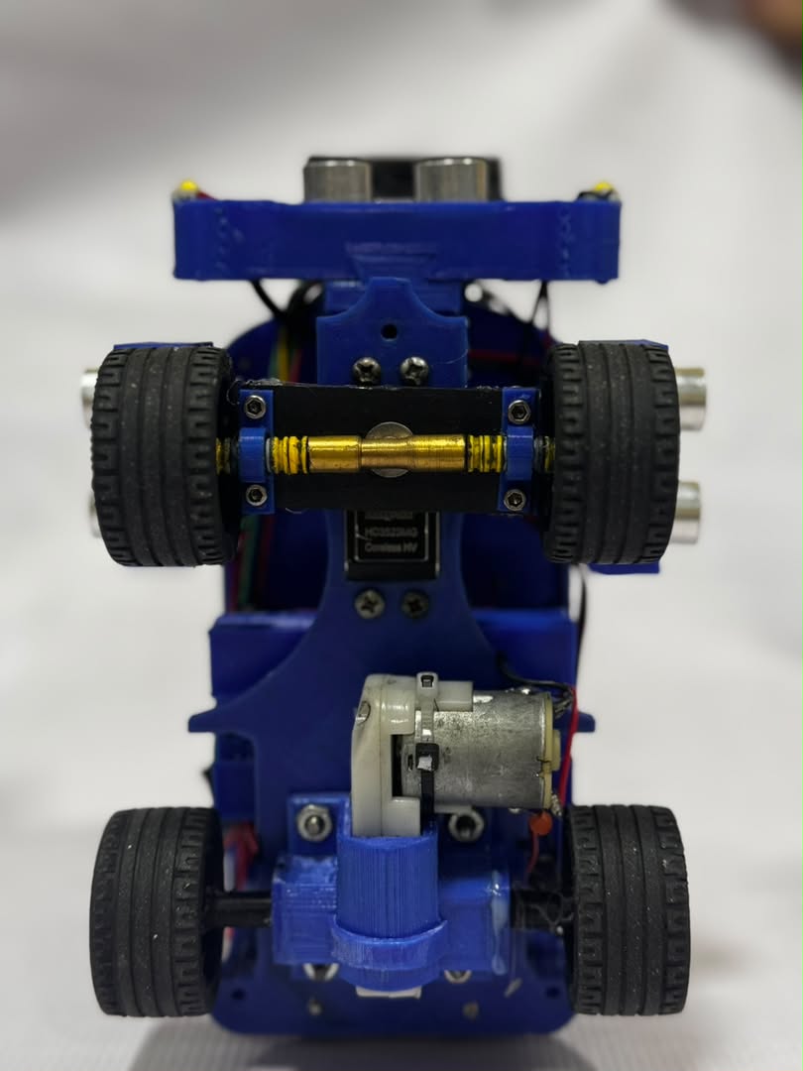
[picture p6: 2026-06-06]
Trivilyn 360/Foto Inferior.jpeg

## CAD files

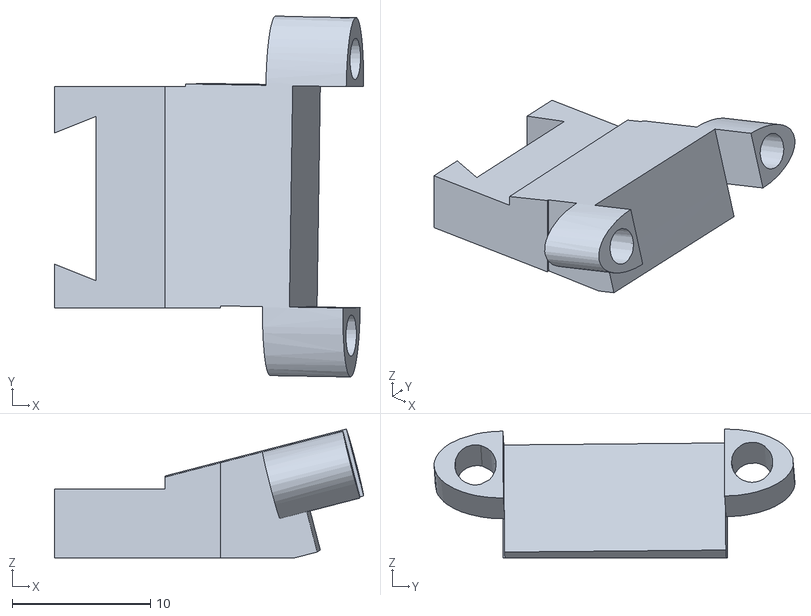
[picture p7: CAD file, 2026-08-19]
Archivos CAD/Base VL53L5X.stl
22.3 x 26.1 x 9.31

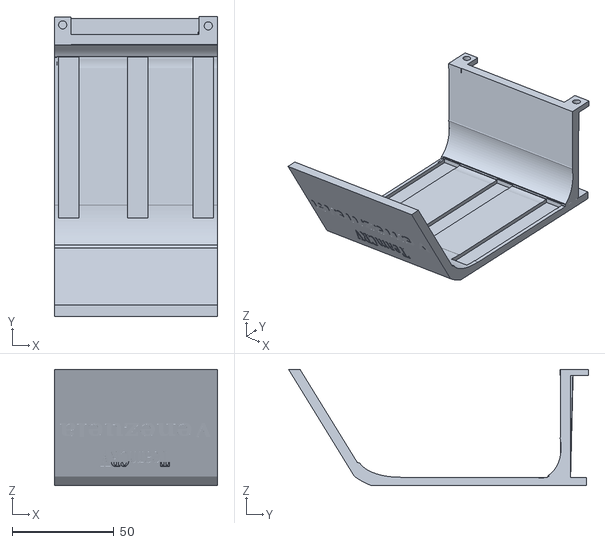
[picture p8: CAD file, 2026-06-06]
Archivos CAD/Tercer piso.stl
80.1 x 147.1 x 57.0

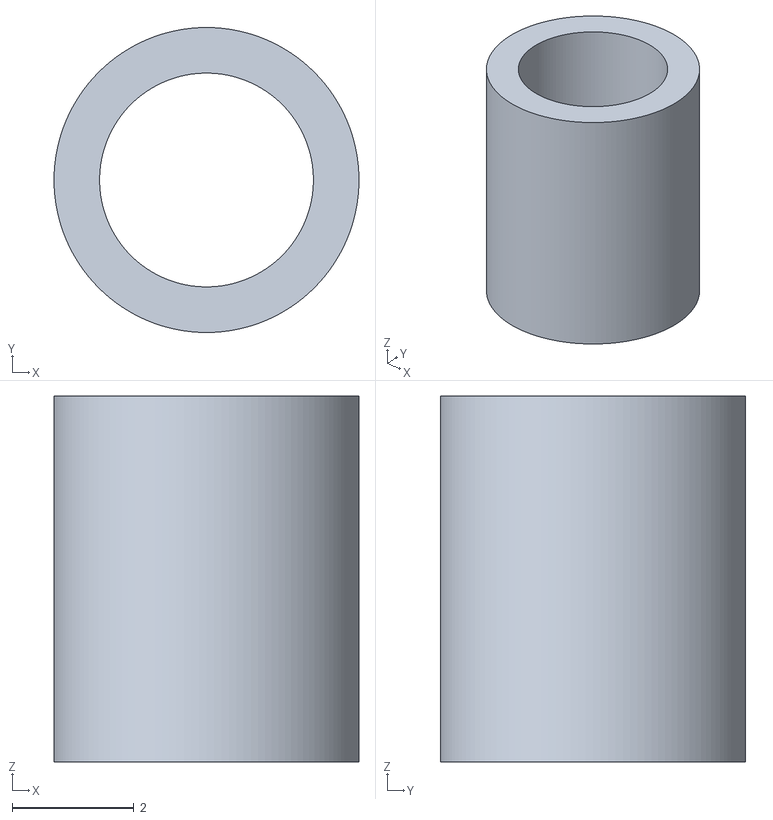
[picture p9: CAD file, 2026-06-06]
Archivos CAD/Espaciadores de elevador.stl
5.00 x 5.00 x 6.00

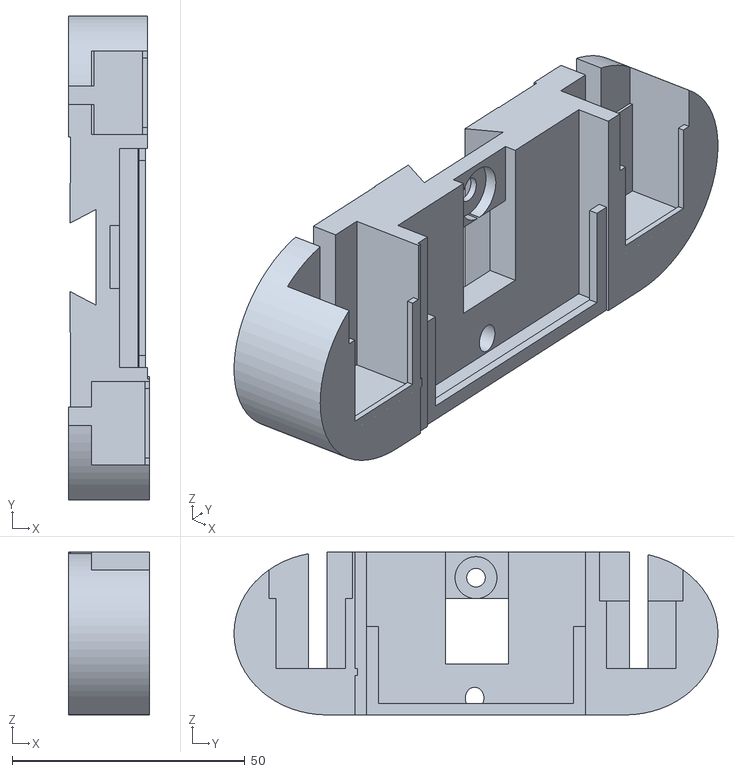
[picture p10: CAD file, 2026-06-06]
Archivos CAD/Base sensor frontal.stl
17.5 x 104.0 x 35.0

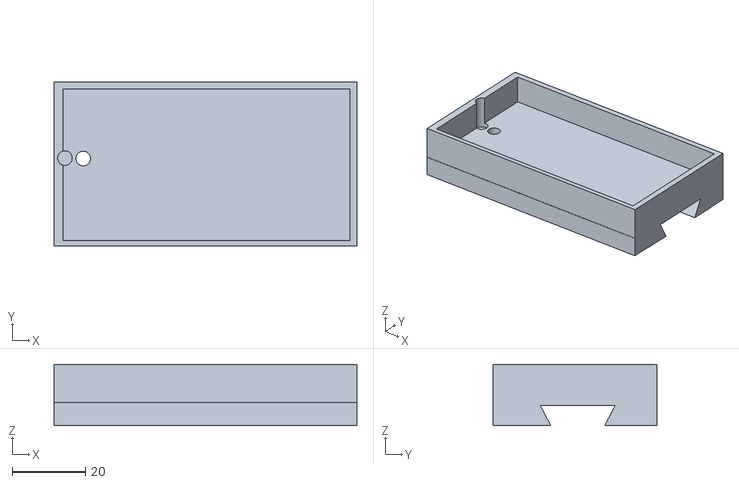
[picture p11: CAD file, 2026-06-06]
Archivos CAD/Riel Hembra Cola de milano.stl
83.0 x 45.0 x 16.8

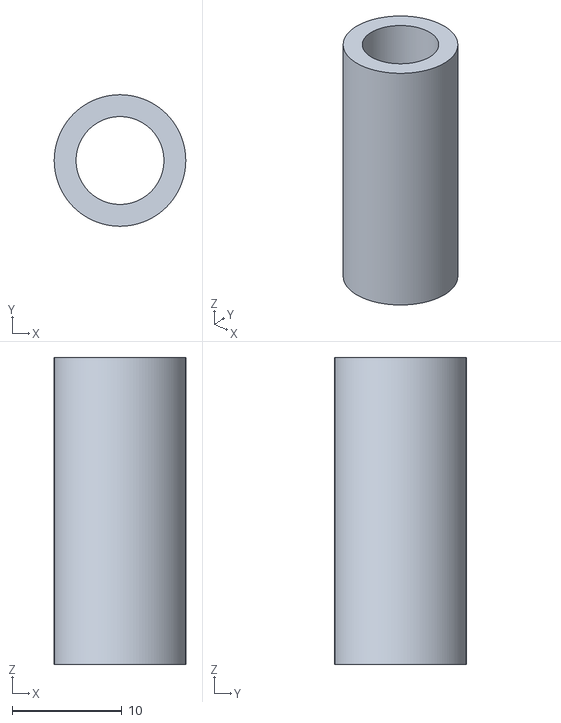
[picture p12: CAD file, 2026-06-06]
Archivos CAD/Tubo Transversal.stl
12.0 x 12.0 x 28.0

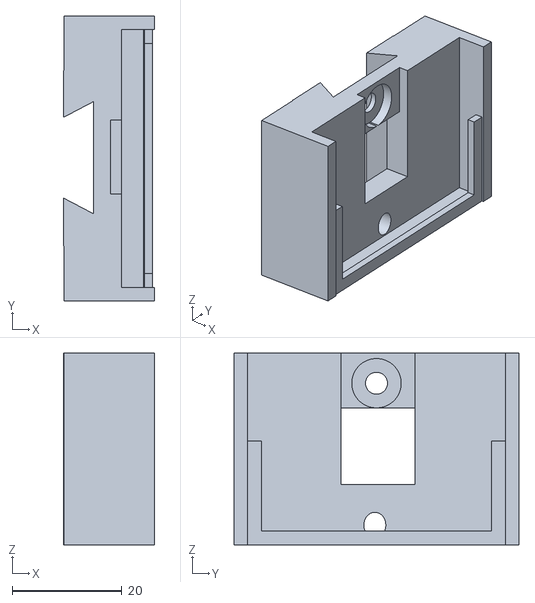
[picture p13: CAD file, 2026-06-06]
Archivos CAD/Base sensor lateral.stl
16.6 x 52.0 x 35.0

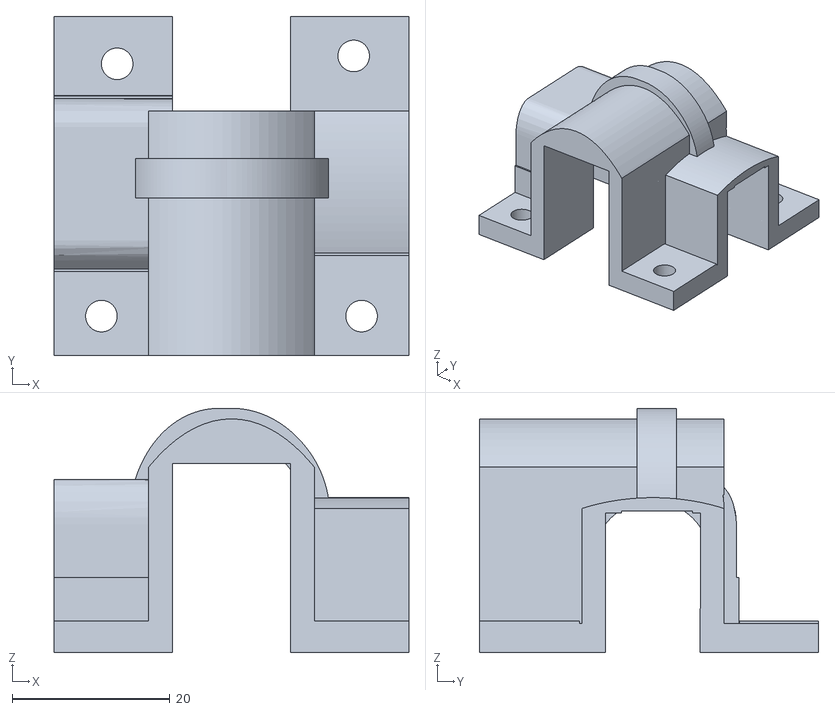
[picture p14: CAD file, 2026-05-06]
Archivos CAD/Soporte Caja de Engranajes.stl
45.0 x 43.0 x 31.0

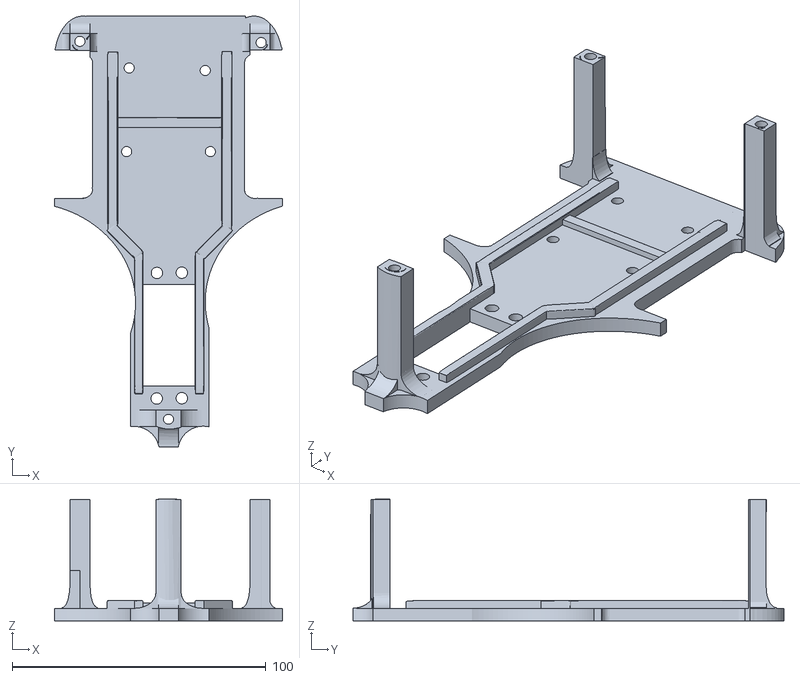
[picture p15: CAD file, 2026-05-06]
Archivos CAD/Primer Piso.stl
90.0 x 170.0 x 48.1

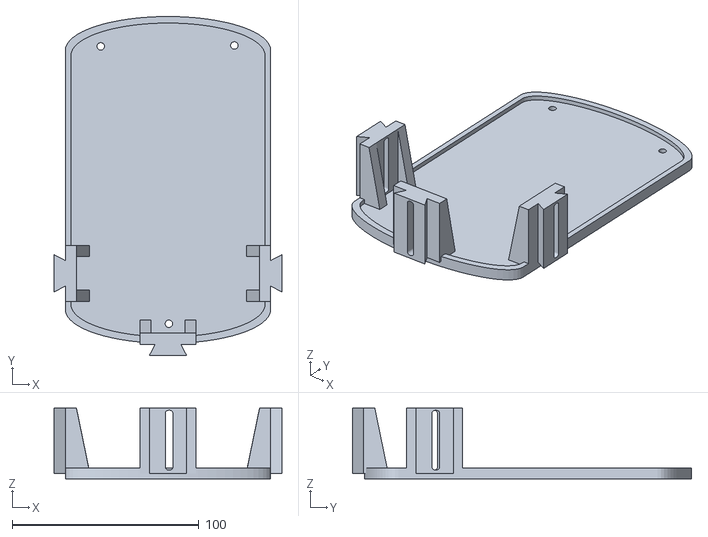
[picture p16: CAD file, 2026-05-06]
Archivos CAD/Segundo Piso.stl
122.0 x 181.5 x 38.0

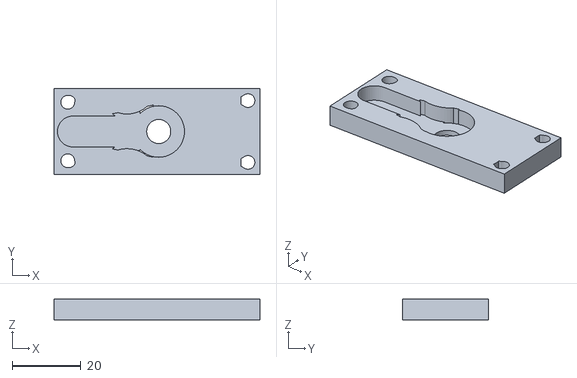
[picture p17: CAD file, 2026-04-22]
Archivos CAD/Soporte Tren Delantero.stl
60.0 x 25.0 x 6.00

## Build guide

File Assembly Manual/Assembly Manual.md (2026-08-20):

# 📑 Especificación de Ingeniería y Manual de Ensamblaje Avanzado: Trivilyn 3.0
### **TEAMROBOTICACRV | World Robot Olympiad - Future Engineers 2026**

   

Este documento técnico de ingeniería detalla de forma exhaustiva, rigurosa y secuencial el protocolo de montaje mecánico, integración de hardware, ciencia de materiales y calibración física del chasis autónomo **Trivilyn 3.0**. El diseño rompe con los esquemas convencionales al implementar una arquitectura modular de tres niveles (capas desacopladas de geometría plana) diseñada específicamente para neutralizar interferencias, optimizar el centro de masa y garantizar el mantenimiento de alta velocidad en pits.

---

## 🏛️ 1. Filosofía de Diseño: Arquitectura de Capas Desacopladas

El chasis del **Trivilyn 3.0** no es un mero soporte pasivo para los componentes; ha sido concebido bajo el paradigma de **Arquitectura de Capas Desacopladas por Niveles**. Esta decisión de ingeniería responde directamente a la necesidad de aislar y mitigar tres variables críticas que degradan el rendimiento de los vehículos autónomos de competencia:

1.  **Vibraciones Mecánicas de Alta Frecuencia:** Inducidas por el motor DC principal operando a regímenes superiores a las 13,000 RPM.
2.  **Disipación Térmica Selectiva:** El calor generado por la etapa de potencia (drivers y motores) debe evacuarse sin calentar los componentes de procesamiento lógico central.
3.  **Ruido Electromagnético (EMI):** El parpadeo magnético y la conmutación de alta corriente de los motores generan ruido que corrompe los buses de datos de alta velocidad ($\text{I}^2\text{C}$ y UART) de la cámara HuskyLens y la red tri-sensorial ultrasónica.

<div align="center">
  Vista Explotada de Ingeniería - Trivilyn 3.0
  <p><i>Figura 1: Vista explotada del ensamble modular multinivel donde se aprecia la segregación física de los tres pisos y los pilares prismáticos de elevación.</i></p>
</div>

* **Planta Baja (Nivel de Actuación y Fuerza):** Alberga la planta propulsora, el servomotor de dirección y el puente H L298N. Soporta los esfuerzos de tracción y corte.
* **Segundo Piso (Nivel de Energía y Percepción):** Aloja el banco de baterías principal (baterías de potencia y lógica) junto con la matriz ajustable de sensores ultrasónicos. Actúa como escudo dieléctrico y magnético.
* **Tercer Piso (Nivel de Procesamiento Lógico Central):** Posiciona el microcontrolador en la coordenada Z más alta, maximizando la refrigeración convectiva y protegiéndolo de transitorios eléctricos.

---

## 🔬 2. Ciencia de Materiales y Optimización de Manufactura Aditiva (FDM)

La integridad estructural del vehículo depende críticamente de la configuración del laminador (*slicer*) y las propiedades intrínsecas del polímero utilizado. Tras pruebas en boxes durante la temporada pasada, el equipo prohibió el uso de PLA en elementos de carga debido a su baja resistencia al impacto y su propensión a la deformación plástica bajo stress térmico.

### 2.1 Polímero de Ingeniería: PETG Industrial
La totalidad de los componentes estructurales (base crema, segundo piso naranja, tercer piso amarillo y espaciadores) han sido fabricados en **PETG (Polietileno de Tereftalato Glicolado)** debido a sus ventajas mecánicas:
* **Temperatura de Transición Vítrea ($T_g$):** $\approx 80^\circ\text{C}$. Esto garantiza que la base del motor no sufra deflexión o ablandamiento cuando el motor disipe calor por fricción prolongada.
* **Tenacidad e Isotropía:** El PETG posee una excelente adhesión interlaminar, reduciendo el riesgo de delaminación (separación de capas) ante impactos transversales contra las defensas de la pista.

### 2.2 Parámetros Técnicos de Impresión de Alta Resistencia
Para neutralizar la anisotropía inherente a la impresión 3D FDM, se estandarizó la siguiente matriz de configuración en el software de laminación:

* **Patrón de Relleno (*Infill*):** **Giroide (Gyroid) al 40% de densidad en todas las piezas del carrito.** El patrón giroide proporciona una resistencia tridimensional homogénea. A diferencia de los patrones rectilíneos o cúbicos, la estructura giroide disipa las fuerzas de torsión por igual en los ejes $X$, $Y$ y $Z$, absorbiendo las vibraciones armónicas del motor sin fisurarse.
* **Conteo de Perímetros:** 4 paredes perimetrales reforzadas con boquilla de 0.4 mm (espesor de pared mínimo de 1.6 mm). Esto asegura que los taladros y orificios pasantes de los tornillos métricos agarren sobre plástico sólido y no sobre el relleno hueco.

---

## ⚙️ 3. Fase I: Planta Propulsora y Tren de Tracción Posterior (Planta Baja)

La plataforma inferior es el cimiento mecánico de Trivilyn 3.0. Debe ensamblarse con tolerancias mínimas para asegurar que no existan desalineaciones en el tren motriz que disipen energía en forma de fricción parásita.

### 3.1 Montaje de la Base del Motor TurboSnake
El motor de corriente continua **TurboSnake** opera en rangos extremos de revolución (entre $13,000$ a $15,000\text{ RPM}$). Cualquier juego en su base destruirá la piñonería de transmisión.

| Componente de Ingeniería | Protocolo de Ensamblaje Mecánico Detallado |
| :--- | :--- |
| Base del Motor - Render CAD | **Alineación Coaxial Absoluta:** Posicione la brida cilíndrica de sujeción del motor (pieza azul) exactamente debajo de la sección trasera calada de la plataforma del chasis principal (pieza crema). Haga coincidir de forma concéntrica los 4 orificios pasantes. Inserte tornillos métricos M3 de acero inoxidable de cabeza Bristol. **Es obligatorio colocar arandelas de presión (*grower*)** entre la cabeza del tornillo y el chasis; de lo contrario, la frecuencia armónica de las 15,000 RPM aflojará las tuercas en carrera. |

### 3.2 Integración del Driver de Potencia L298N
El puente H doble **L298N** se encarga de conmutar los giros y la velocidad mediante señales PWM procedentes de la etapa lógica superior.

| Layout del Puente H Montado | Protocolo de Fijación y Aislamiento Dieléctrico |
| :--- | :--- |
| Driver L298N Montado en Chasis | **Fijación sobre Postes:** Ubique los 4 postes de elevación integrados en la zona posterior de la base crema. Posicione el PCB del driver sobre los postes cuidando la orientación de las borneras de tornillo hacia afuera para facilitar el cableado del bloque del motor. Inserte tornillos métricos de sujeción. Se recomienda el uso de arandelas plásticas aislantes para evitar que las vibraciones desgasten la laca de protección del circuito impreso y causen un cortocircuito estático contra los soportes del chasis. |

---

## 4. Fase II: Sistema de Dirección Electrónica "Steer-by-Wire" (SbW)

Trivilyn 3.0 rompe radicalmente con los esquemas de dirección tradicionales (como la geometría Ackerman). En su lugar, el equipo implementó un sistema puramente **Steer-by-Wire (SbW)** o dirección electrónica digital por cable. No existe una columna de dirección física ni varillaje mecánico complejo que acople las ruedas de forma asimétrica; el ángulo de guiado se calcula por software y se transmite de forma directa e instantánea a través del actuador a los bloques de dirección independientes.

<div align="center">
  Detalle de Acople de Dirección Steer-by-Wire
  <p><i>Figura 2: Encastre de alta tolerancia del sistema Steer-by-Wire. Se aprecia el acoplamiento directo entre la palanca del actuador servo (brazo naranja) y la base de dirección móvil del eje (pieza azul).</i></p>
</div>

### 4.1 Montaje e Interferencia Mecánica del Servo
Para ejecutar el control angular con precisión milimétrica frente a las fuerzas de inercia lateral, utilizamos un servomotor digital **HobbyPark de 35 kg-cm** con piñonería interna de acero.
1.  Inserte el servomotor verticalmente en el alojamiento rectangular delantero del chasis base. El encaje está diseñado por *ajuste por interferencia* (tolerancia de 0.05 mm). El servo debe entrar firmemente a presión.
2.  Si detecta cualquier holgura microscópica en el alojamiento, aplique una capa perimetral de cinta aislante Kapton en las paredes del servo para absorber el juego antes de fijar los tornillos de sujeción lateral.

### 4.2 Protocolo de Calibración del Cero Lógico (Firmware vs Hardware)
El mayor error en boxes es montar el brazo del servo a ciegas. Siga este protocolo estrictamente:
1.  Conecte el servo al Arduino Mega, energice la etapa lógica y parpadee el firmware de calibración estática.
2.  Envíe una señal PWM exacta con un ancho de pulso correspondiente al **centro lógico puro de 94 grados ($1544\mu\text{s}$)**.
3.  Manteniendo el servo energizado y bloqueado electrónicamente en esos 94°, encastre a presión la **Palanca del Servo (pieza naranja)** en el estriado metálico del motor, asegurándose de que encaje perfectamente perpendicular con la **Base de la Dirección (pieza azul)**, tal como se detalla en el recuadro de la *Figura 2*.
4.  Inserte y ajuste el tornillo central del eje estriado a un torque firme para bloquear el conjunto.

> [!IMPORTANT]
> **RELEVANCIA EN EL CONTROL DE LA HUSKYLENS:** Si el acople entre la palanca naranja y la base azul posee juego mecánico (*backlash*), el vehículo sufrirá de oscilación descontrolada (*wobbling*) a alta velocidad. La cámara procesará la línea o el pilar, enviará la corrección al servo, pero debido al juego mecánico el carro no girará de inmediato; el algoritmo sobre-corregirá en el siguiente ciclo, provocando que el robot zigzaguee hasta salirse de la pista. El ajuste a presión elimina este bucle de error.

---

## 5. Fase III: Gestión Energética Modular y Riel "Quick-Change"

La eficiencia en una carrera autónoma no solo se mide en la pista, sino en la velocidad de respuesta del equipo técnico en la zona de boxes. El diseño del carro prioriza que el mantenimiento eléctrico se realice en segundos.

### 5.1 Mecanismo de Acoplamiento en Cola de Milano (Dovetail)
Para alimentar la planta motriz y aislarla del consumo lógico, el robot utiliza bancos independientes. El banco de baterías de potencia se desliza sobre una guía mecánica integrada.
1.  Presente el **Riel Macho** (corredera de baterías) sobre su contraparte hembra en la sección central interaxil de la estructura. El riel macho está integrado estructuralmente en el **segundo piso** del vehículo.
2.  Deslice el módulo para verificar que el recorrido sea suave y no se trabe por imperfecciones en las líneas de impresión FDM.

> [!IMPORTANT]
> **PROTOCOLO DE CURADO QUÍMICO DE ALTA RESISTENCIA:** Limpie las caras de contacto del riel con alcohol isopropílico para remover grasas o filamentos sueltos. Aplique una mezcla homogénea de adhesivo estructural epóxico de dos componentes (**Goma A y Goma B**). Una las piezas y mantenga presión uniforme con prensa durante un mínimo de 12 minutos. *Queda estrictamente prohibido el uso de cianoacrilatos (SuperGlue, pegamento loco)*; al cristalizar, se vuelven quebradizos y las vibraciones continuas del motor TurboSnake romperán la unión, desprendiendo el banco de baterías in carrera.

---

## 6. Fase IV: Segundo Piso (Aislamiento y Red de Percepción)

El segundo nivel (plataforma naranja) cumple una doble función: actúa como escudo de separación magnética y física para las líneas lógicas superiores y aloja los sensores de proximidad de rango medio.

### 6.1 Elevación Prismática Mediante Espaciadores
1.  Aplique adhesivo epóxico de dos componentes (Goma A y B) en los extremos de los **Espaciadores Estructurales Frontales y Posteriores**.
2.  Posiciónelos firmemente en las bahías de anclaje de la base crema inferior.
3.  Superponga la **Segunda Base Electrónica (Bandeja Naranja)** asegurándose de que coincida con los postes de los espaciadores. Ensamble de forma pasante utilizando tornillos autorroscantes M3 para unificar rígidamente ambos pisos en una estructura monocasco virtual.

### 6.2 Matriz Sensorial de Ultrasonido Ajustable por Corredera
El robot utiliza sensores **HC-SR04** para mapear la distancia lateral respecto a los muros perimetrales y evitar colisiones destructivas.
1.  Ensamble el bloque de la **Corredera Hembra del Sensor Ultrasónico** en el riel vertical del chasis. El ajuste debe permitir el desplazamiento con resistencia táctil.
2.  Inserte los transductores ultrasónicos a presión in sus respectivas cunas.

> [!TIP]
> **CALIBRACIÓN GEOMÉTRICA DE ALTURA (FOV DEL ULTRASONIDO):** Deslice la corredera verticalmente hasta garantizar que el eje acústico central de los transductores sea perfectamente paralelo a la superficie del suelo y perpendicular al plano del muro. Si el sensor queda apuntando ligeramente hacia abajo, el haz ultrasónico rebotará contra el suelo provocando lecturas de "falsos positivos" (el robot creerá que tiene un muro enfrente y frenará). Si queda apuntando hacia arriba, el haz pasará de largo en muros bajos provocando colisiones inminentes.

3.  Aloje los dos compartimientos porta-baterías para celdas **18650** de forma horizontal sobre la superficie del segundo piso. Su ubicación horizontal distribuye de manera simétrica los momentos de inercia transversal cuando el carro realiza giros cerrados controlados por el sistema Steer-by-Wire.

---

## 🧠 7. Fase V: Tercer Piso (Procesamiento Analítico y Visión de Máquina)

El plano de mayor elevación geométrica de Trivilyn 3.0 está dedicado exclusivamente a la computación lógica de alto nivel. Aquí es donde se ejecuta el bucle principal de control de 32 bits, el procesamiento de la cámara inteligente HuskyLens y la toma de decisiones evasivas a alta velocidad.

| Componente Estructural Superior Real | Protocolo de Instalación Lógica Central |
| :--- | :--- |
| ESP32 Montado en Tercer Piso Amarillo | **Fijación Dieléctrica del SoC:** Monte la placa del **Tercer Piso (Placa Amarilla)** utilizando los tres puntos de atornillado correspondientes sobre las columnas estructurales elevadas. Posicione el microcontrolador **ESP32 (32 bits)** sobre sus guías perimetrales exactas. Asegure la placa firmemente insertando sus respectivos tornillos de montaje directos sobre la base. La elevación prismática de este tercer piso amarillo es una decisión de ingeniería crítica: permite crear una cámara de aire para la disipación térmica por convección pasiva del SoC y lo mantiene aislado de los campos electromagnéticos parásitos (EMI) generados por la planta motriz e inductancias del driver L298N en los pisos inferiores. |

> [!IMPORTANT]
> **ENRUTAMIENTO DE BUSES DE DATOS Y LÓGICA DE 3.3V:** Al conectar la cámara HuskyLens (vía Hardware Serial `Serial1` en GPIO 16/4), el sensor ToF VL53L5CX (vía $\text{I}^2\text{C}$ Fast Mode en GPIO 25/26) y los sensores ultrasónicos a las líneas del ESP32, asegúrese de trenzar físicamente los cables de señal o utilizar líneas blindadas de longitud mínima. Dado que el ESP32 opera con tolerancia nativa a **3.3V**, estas líneas de datos jamás deben correr en paralelo con los cables de alta corriente de la batería que alimentan el driver L298N ni con los pulsos de potencia del servomotor, evitando ruidos inductivos que puedan congelar el bus $\text{I}^2\text{C}$ o corruptar los paquetes en plena carrera.

## 🧪 8. Protocolo de Mantenimiento Químico y Lubricación de Polímeros

El coeficiente de fricción inter-componente en piezas móviles fabricadas por FDM puede reducir drásticamente el par de torsión neto y drenar la carga útil de las baterías de litio. Sin embargo, la aplicación del lubricante incorrecto destruirá el vehículo mecánicamente.

> [!CAUTION]
> **ADVERTENCIA QUÍMICA ABSOLUTA - AGRIETAMIENTO POR STRESS AMBIENTAL (ESC):**
> **¡QUEDA ESTRICTAMENTE PROHIBIDO EL USO DE GRASAS INDUSTRIALES COMUNES, ACEITES DE MOTOR, LUBRICANTES AZULES O COMPUESTOS CON BASE DE LITIO!**
> Los hidrocarburos aromáticos y solventes presentes en los lubricantes minerales industriales penetran en la microestructura porosa de los polímeros impresos en 3D (tanto en el PLA como en el PETG). Este proceso rompe las fuerzas de Van der Waals entre las cadenas del polímero, desencadenando el fenómeno conocido como **Agrietamiento por Estrés Ambiental (ESC)**. Bajo carga de trabajo, las piezas lubricadas con estos aceites sufrirán fallas estructurales catastróficas instantáneas, quebrando los dientes del diferencial mecánico y las articulaciones de la dirección.
> 
> **SOLUCIÓN EXCLUSIVA DE INGENIERÍA:** Aplique única y exclusivamente una fina capa homogénea de **Vaselina Neutra** (petrolato puro de grado medicinal) o lubricantes secos basados en PTFE (Teflón). La vaselina es un compuesto hidrocarbonado saturado de alta cadena que resulta **100% químicamente inerte** ante la estructura molecular del PETG y del PLA, reduciendo la fricción parásita a cero sin degradar los componentes.

---

## ✅ 9. Check-list de Inspección Técnico Pre-Vuelo (Protocolo de Boxes)

Antes de colocar el Trivilyn 3.0 en la línea de partida para una ronda oficial, el equipo de pits debe verificar obligatoriamente este protocolo de verificación de cuatro puntos críticos:

- [ ] **Masa Común Unificada (GND Link):** Comprobar con un multímetro digital la continuidad eléctrica absoluta entre el borne negativo de la batería de potencia (motor) y el pin GND de la placa lúdica Arduino Mega. Una masa flotante generará ruido eléctrico que alterará las lecturas analógicas de los sensores.
- [ ] **Calibración de Neutro SbW:** Energizar el vehículo y validar mediante el monitor serial que el servomotor esté recibiendo la señal exacta de centro a **94 grados**, asegurando que las ruedas delanteras queden perfectamente paralelas ($90^\circ$) respecto al eje longitudinal central del chasis.
- [ ] **Torque Estático de Fijación:** Verificar visual y mecánicamente el apriete de los 4 tornillos M3 de la brida azul del motor TurboSnake y el tornillo central del brazo del servo.
- [ ] **Despeje de Líneas de Fuerza:** Inspeccionar que ningún cable de datos roce o esté expuesto a la zona de fricción abierta del piñón de ataque del tren de tracción posterior o del diferencial mecánico de engranajes planetarios.

---
**Documentación Técnico de Ingeniería de Competición generada por TEAMROBOTICACRV.**
**Filosofía de Escudería 2026: *"Adaptarse para ganar"*. Todos los derechos reservados.**

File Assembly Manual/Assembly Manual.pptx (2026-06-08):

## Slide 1

Colocar la base del motor debajo de la ase principal en modo que queden alineados sus 4 agujeros para sus tornillos.

Base principal

Base del motor

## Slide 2

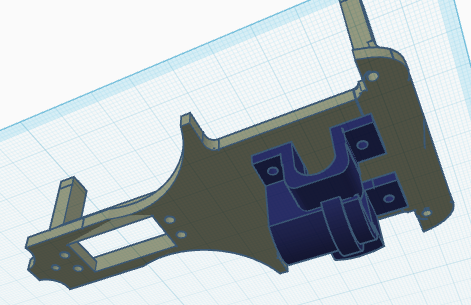
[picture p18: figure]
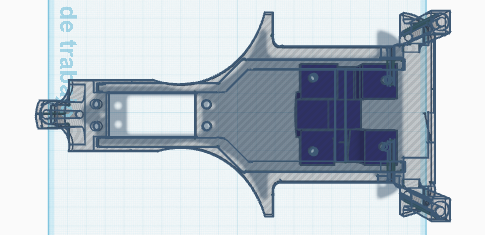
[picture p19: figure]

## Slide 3

Servo motor Hobby Park

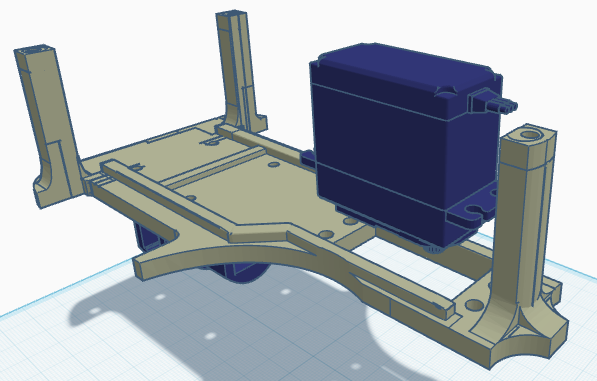
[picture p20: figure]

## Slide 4

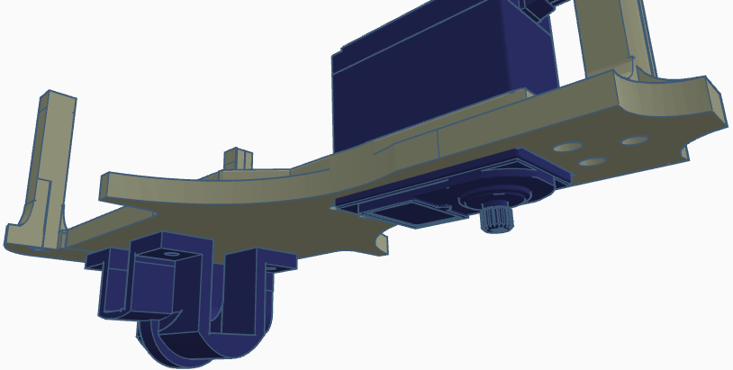
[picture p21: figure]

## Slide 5

Driver L298N

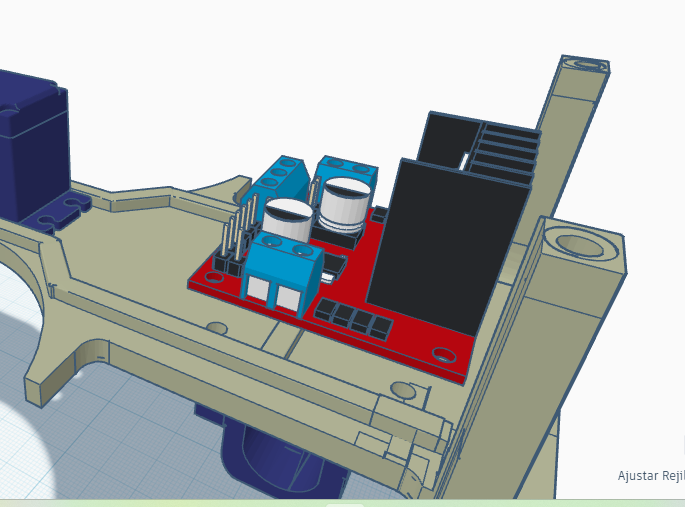
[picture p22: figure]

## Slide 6

Corredera macho baterías

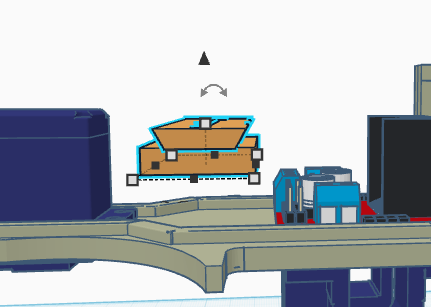
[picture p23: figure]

Se coloca la corredera a la base principal entre el ser vo motor y el driver, se adiere con goma “A y B”

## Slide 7

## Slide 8

Espaciador frontal

Espaciador posterior

Colocar espaciadores y adherir con adhesivo “A y B”

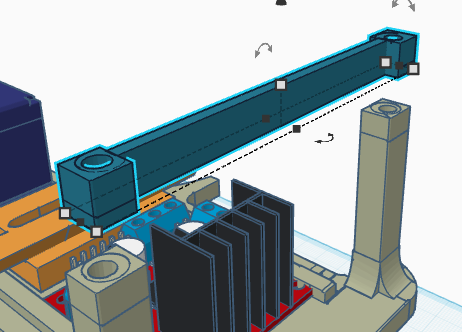
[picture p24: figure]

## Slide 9

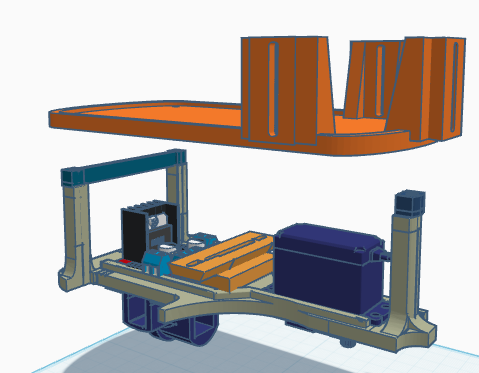
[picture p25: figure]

Atornillar segunda base junto a los espaciadores y base principal

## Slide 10

Corredera hembra sensor ultrasónico

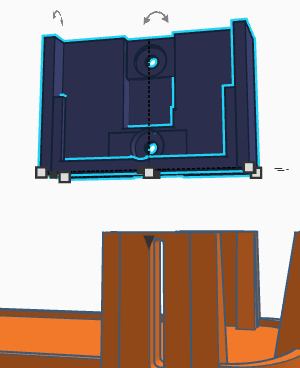
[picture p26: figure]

Que quede de la siguiente forma

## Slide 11

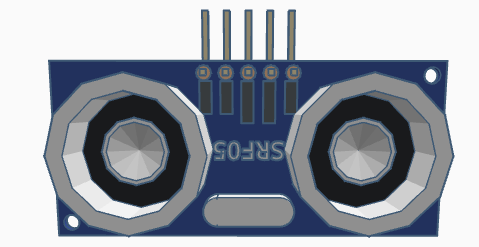
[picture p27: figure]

Sensor ultrasónico

Se coloca en el encastre de la siguiente manera

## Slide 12

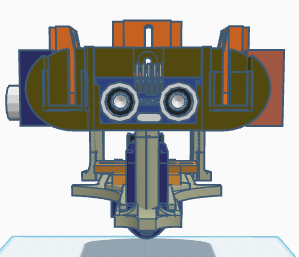
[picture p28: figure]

De igual manera el frontal

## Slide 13

Porta baterías 18650

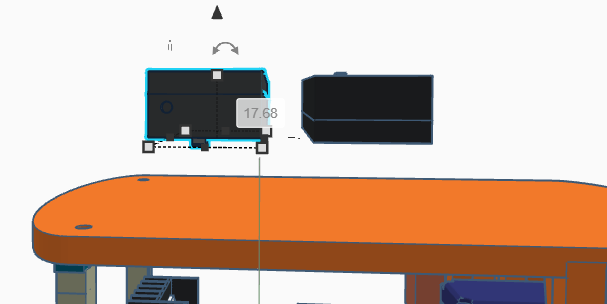
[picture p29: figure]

Se colocan ambos porta baterías de 18650 en el segundo piso.

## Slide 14

Tercer piso

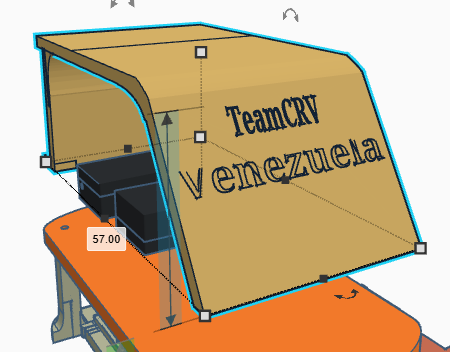
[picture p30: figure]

Se coloca el tercer piso y se atornilla en sus 3 agujeros correspondientes

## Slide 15

Así debería ir quedando triilyn.0

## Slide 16

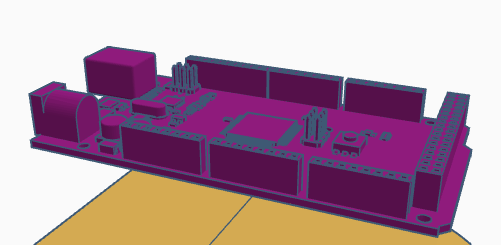
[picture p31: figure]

Arduino mega

Colocamos el arduino mega con sus respectivos tornillos

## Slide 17

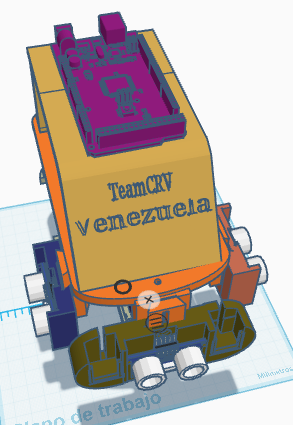
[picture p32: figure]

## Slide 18

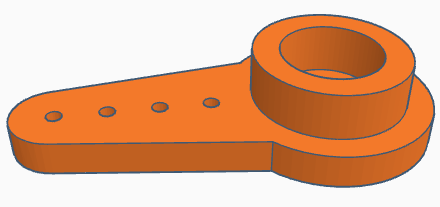
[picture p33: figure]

Palanca del servo

Se coloca la palanca del servo

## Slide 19

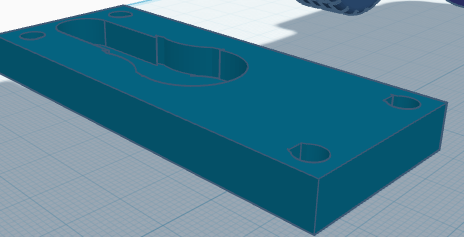
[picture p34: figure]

Base de la dirección

Se coloca de modo que encajen ambas piezas y se ajusta con un tornillo central

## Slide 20

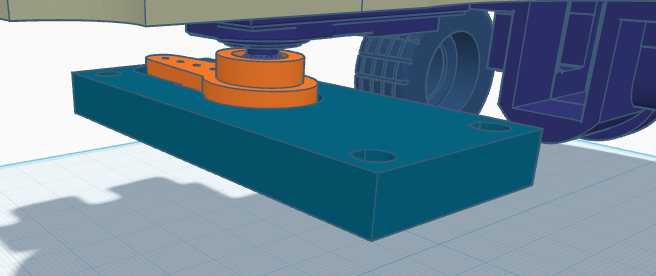
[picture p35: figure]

Que quede de esta manera

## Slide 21

Soporte eje

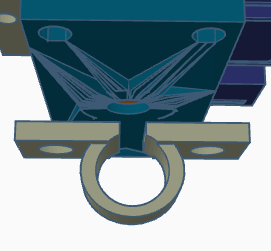
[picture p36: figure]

Se fijan de la siguiente manera con tornillos, del lado izquierdo y derecho

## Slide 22

Que quede de la siguiente manera

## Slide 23

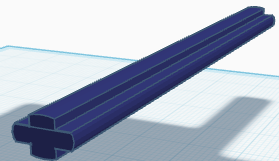
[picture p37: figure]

Ejes de lego

Encajamos ambos ejes de la siguiente manera

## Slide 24

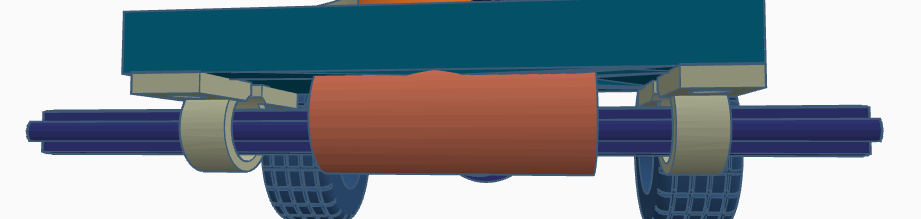
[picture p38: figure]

Colocamos el diferencial justo en el medio

Diferencial

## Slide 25

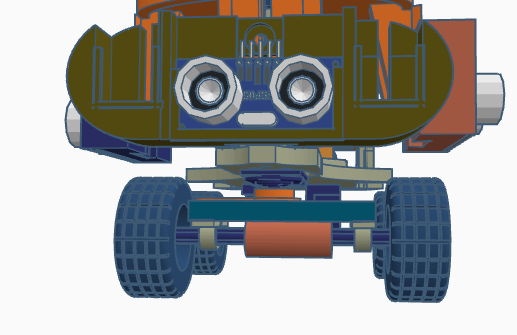
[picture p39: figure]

Colocamos las 4 ruedas de lego

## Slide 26

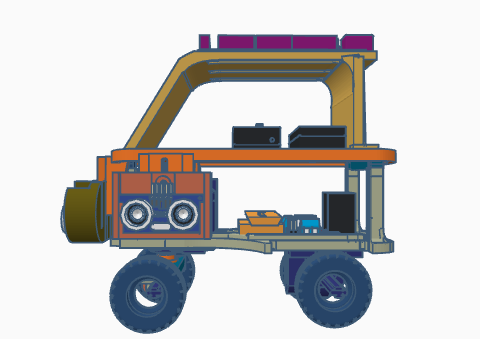
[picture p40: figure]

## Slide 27

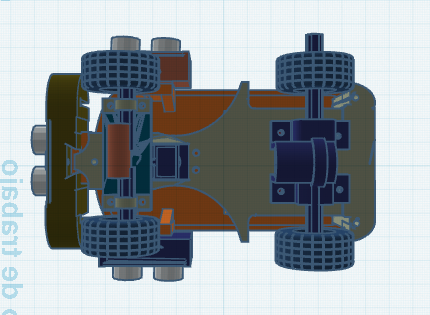
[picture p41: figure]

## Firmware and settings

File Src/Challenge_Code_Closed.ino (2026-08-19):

#include <ESP32Servo.h>
#include <NewPing.h> // Biblioteca para los sensores ultrasónicos

Servo myservo; //servo control

#include "HUSKYLENS.h"

// Izquierdo: TRIG=17, ECHO=18
// Derecho:   TRIG=22, ECHO=23
#define TRIG_LEFT   17
#define ECHO_LEFT   18
#define TRIG_RIGHT  22
#define ECHO_RIGHT  23

int ID1 = 1;
int ID2 = 2;
int ID3 = 3;
int ID4 = 4;
int ID5 = 5;
int ID6 = 6;

#define HUSKY_SERIAL Serial1
#define HUSKY_RX 16
#define HUSKY_TX 4
HUSKYLENS huskylens;
void printResult(HUSKYLENSResult result);

int carSpeed = 58;
int carSpeedColor = 100;
int carSpeedCurvas = 100;
int backk = 85;
int centro = 87;
int centroA = 87;
int centroH = 87;
int contadorLecturas = 0;
int winnie = 0;
int winnieV = 0;
int pepe = 0;
int tilin = 0;
int grasa = 0;
int lewis = 0;
int lecrer = 0;
int senna = 0;
int nano = 0;

#define ENA 13
#define IN1 14
#define IN2 27

#define TRIGGER_PIN  19 
#define ECHO_PIN     21 

#define MAX_DISTANCE 400

  NewPing sonar(TRIGGER_PIN, ECHO_PIN, MAX_DISTANCE);
  NewPing sonarLeft(TRIG_LEFT, ECHO_LEFT, MAX_DISTANCE);
  NewPing sonarRight(TRIG_RIGHT, ECHO_RIGHT, MAX_DISTANCE);

// leftDistance y rightDistance en milímetros (ultrasónico lateral, convertido desde cm).
// middleDistance sigue en centímetros (sonar ultrasónico frontal).
int rightDistance = 0, leftDistance = 0, middleDistance = 0;


int getDistance() {
delay(50);
  Serial.print("Ping: ");
  Serial.print(sonar.ping_cm());
  Serial.println("cm");
}

int leerUltrasonico(NewPing &sensor){
  unsigned int cm = sensor.ping_cm();
  if (cm == 0){ // 0 = fuera de rango / sin eco
    return 9999; // fuera de rango: valor alto (mm) para no disparar la lógica de esquiva
  } else {
    return cm * 10; // cm -> mm
  }
}

unsigned long ultimaEsquivaMillis = 0;
const unsigned long COOLDOWN_ESQUIVA_MS = 1500;

void stop(){
  digitalWrite(IN1,LOW);
  digitalWrite(IN2,LOW);
}
void back(){
  analogWrite(ENA,backk);
  digitalWrite(IN1,LOW);
  digitalWrite(IN2,HIGH);
  Serial.print("Back");
  }

void forward(){
  analogWrite(ENA,carSpeed);
  digitalWrite(IN1,HIGH);
  digitalWrite(IN2,LOW);
  Serial.print("Forward- ");
  Serial.println(middleDistance);
}
  void freno(){
  analogWrite(ENA,55);
  digitalWrite(IN1,LOW);
  digitalWrite(IN2,HIGH);
  delay(200);
  Serial.print("Back");
  }


void izquierda(){//antihorario
delay(500);
  myservo.write(centro);
        back();
      delay(500);
  myservo.write(121);
    delay(970);
    myservo.write(centroA);
    forward();
  }

void derecha(){//horario
delay(500);
  myservo.write(centro);
        back();
      delay(400);
    myservo.write(58);
    delay(1250);
         myservo.write(centroH);
    forward();
  }

   void esquivarObjetoMuyDerecha(){
    forward();
    delay(300);
  }

     void esquivarObjetoMuyIzquierda(){
    forward();
    delay(300);
  }

  void rojocentro(){
 myservo.write(123);
analogWrite(ENA,carSpeedColor);
delay(400);
myservo.write(63);
delay(800);
myservo.write(123);
delay(400);
myservo.write(centro);
  }

  void rojoderecha(){
myservo.write(121);
analogWrite(ENA,carSpeedColor);
delay(580);
myservo.write(58);
delay(1200);
myservo.write(123);
delay(550);
myservo.write(centro);
  }

    void Rojolargo(){
myservo.write(123);
analogWrite(ENA,carSpeedColor);
delay(690);
myservo.write(58);
delay(1420);
myservo.write(123);
delay(600);
myservo.write(centro);
  }

   void rojoizquierda(){
 myservo.write(123);
analogWrite(ENA,carSpeedColor);
delay(300);
myservo.write(63);
delay(800);
myservo.write(123);
delay(300);
myservo.write(centro);
  }

  void verdeizquierda(){
myservo.write(59);
analogWrite(ENA,carSpeedColor);
delay(700);
myservo.write(125);
delay(1120);
myservo.write(63);
delay(780);
myservo.write(centro);
  }

    void Verdelargo(){
myservo.write(65);
analogWrite(ENA,carSpeedColor);
delay(700);
myservo.write(120);
delay(1170);
myservo.write(63);
delay(750);
myservo.write(centro);
 stop();
 delay(500);
  }

void verdederecha(){
myservo.write(68);
analogWrite(ENA,carSpeedColor);
delay(550);
myservo.write(123);
delay(600);
myservo.write(63);
delay(500);
myservo.write(centro);
  }

  void verdecentro(){
myservo.write(68);
analogWrite(ENA,carSpeedColor);
delay(650);
myservo.write(123);
delay(700);
myservo.write(63);
delay(600);
myservo.write(centro);
  }

   void rojoderechaA(){
myservo.write(123);
analogWrite(ENA,carSpeedColor);
delay(500);
myservo.write(58);
delay(1150);
myservo.write(123);
delay(500);
myservo.write(centroA);
  }

    void RojolargoA(){
myservo.write(123);
analogWrite(ENA,carSpeedColor);
delay(650);
myservo.write(58);
delay(1420);
myservo.write(123);
delay(700);
myservo.write(centro);
      stop();
      delay(1000);
  }

   void rojoizquierdaA(){
 myservo.write(121);
analogWrite(ENA,carSpeedColor);
delay(300);
myservo.write(63);
delay(800);
myservo.write(123);
delay(350);
myservo.write(centroA);
  }

  void verdeizquierdaA(){
myservo.write(58);
analogWrite(ENA,carSpeedColor);
delay(650);
myservo.write(118);
delay(1000);
myservo.write(63);
delay(700);
myservo.write(centroA);
  } 

    void VerdelargoA(){
myservo.write(66);
analogWrite(ENA,carSpeedColor);
delay(700);
myservo.write(118); 
delay(1170);
myservo.write(63);
delay(600);
myservo.write(centroA);
         stop();
      delay(1000);
  }

void verdederechaA(){
myservo.write(68);
analogWrite(ENA,carSpeedColor);
delay(550); 
myservo.write(123);
delay(550);
myservo.write(63);
delay(500);
myservo.write(centroA);
  }


void setup() {
  Serial.begin(115200);
    HUSKY_SERIAL.begin(9600, SERIAL_8N1, HUSKY_RX, HUSKY_TX);
    while (!huskylens.begin(HUSKY_SERIAL))
    {
        Serial.println(F("Begin failed!"));
        Serial.println(F("1.Please recheck the \"Protocol Type\" in HUSKYLENS (General Settings>>Protocol Type>>Serial 9600)"));
        Serial.println(F("2.Please recheck the connection."));
        delay(100);
    }
  myservo.attach(32);
  pinMode(IN1,OUTPUT);
  pinMode(IN2,OUTPUT);
  pinMode(ENA,OUTPUT);
}


void loop(){
analogWrite(ENA, carSpeed);
if (pepe==0){
  myservo.write(80);
  delay(1000);
  myservo.write(centro);
  delay(1000);
  forward(); 
  forward();
  pepe++;
}

forward();

if (pepe>12){
  delay(1);
  forward();
   myservo.write(centro);
  delay(1000);
  stop();
  delay(1000000000);
}


middleDistance = sonar.ping_cm();
leftDistance = leerUltrasonico(sonarLeft);
rightDistance = leerUltrasonico(sonarRight);

bool cooldownListo = (millis() - ultimaEsquivaMillis) > COOLDOWN_ESQUIVA_MS;
if ((middleDistance <= 7 && middleDistance > 1) && cooldownListo){
       analogWrite(ENA, 110);
Serial.println(middleDistance);

forward();
  pepe++;

  Serial.println(leftDistance);
  Serial.println(rightDistance);
   if (leftDistance < rightDistance && grasa == 0){
      tilin++;
      lecrer++;
   }
   else if (leftDistance > rightDistance && tilin == 0){
    grasa++;
    lewis++;
   }

    if (tilin > 0 && grasa == 0 && lecrer >= 0){
      derecha();
      ultimaEsquivaMillis = millis();
    }   
     else if (grasa > 0 && lewis >= 0){
    izquierda();
      senna++;
      ultimaEsquivaMillis = millis();
}
 }   
   if (leftDistance <= 390 && leftDistance > 100 && pepe > 0 ){
  myservo.write(104);
   delay(30);
    myservo.write(centro);
    }
   if(rightDistance <= 390 && rightDistance > 100 && pepe > 0){
      myservo.write(70);
    delay(30);
    myservo.write(centro);
}
delay(100);


 analogWrite(ENA, carSpeed); 
 if (pepe==0){
   myservo.write(70);
   delay(800);
   myservo.write(centro);
  pepe++;
 }

if (huskylens.request())
    {
   Serial.println("###################################");
        Serial.println(String()+F("Count of learned IDs:")+huskylens.countLearnedIDs());
        Serial.println(String()+F("frame number:")+huskylens.frameNumber());

        Serial.println("#######");
        Serial.println(String()+F("Get all blocks and arrows. Count:")+huskylens.count());
        for (int i = 0; i < huskylens.count(); i++)
        {
            HUSKYLENSResult result = huskylens.get(i);
            printResult(result);
        }
    }
    else{
        Serial.println("Fail to request objects from Huskylens!");
    }

delay(50);
}

void printResult(HUSKYLENSResult result){
    if (result.command == COMMAND_RETURN_BLOCK){//result is a block
        Serial.println(String()+F("Block:xCenter=")+result.xCenter+F(",yCenter=")+result.yCenter+F(",width=")+result.width+F(",height=")+result.height+F(",ID=")+result.ID);
        Serial.println(result.ID);
    }
    else if (result.command == COMMAND_RETURN_ARROW){//result is an arrow
        Serial.println(String()+F("Arrow:xOrigin=")+result.xOrigin+F(",yOrigin=")+result.yOrigin+F(",xTarget=")+result.xTarget+F(",yTarget=")+result.yTarget+F(",ID=")+result.ID);
    }

  //FLANCO DERECHO
    if (result.ID == 1 && result.height>57 && result.xOrigin >= 160 && result.xOrigin <270 && senna <= 0) {
        Serial.println("-------------red -----------");//avoid for right
      rojoderecha();
          delay(winnie);
  }


    //FLANCO DERECHO
     else if (result.ID == 2 && result.height>57 && result.xOrigin >= 160 && result.xOrigin <270 && senna <= 0) {
        Serial.println("-------------red -----------");//avoid for right
      rojoderecha();
          delay(winnie);
  }  

     //FLANCO DERECHO
     else if (result.ID == 3 && result.height>57 && result.xOrigin >= 160 && result.xOrigin <270 && senna <= 0) {
        Serial.println("-------------red -----------");//avoid for right
      rojoderecha();
          delay(winnie);
  }  
  //Largo Largo 
  if (result.ID == 1 && result.height>62 && result.xOrigin > 270 && senna <= 0) {
    Serial.print("Color detectado en la extrema derecha. X: ");
    Serial.println(result.xCenter);
    
        Rojolargo();
}
if (result.ID == 2 && result.height>62 && result.xOrigin > 270 && senna <= 0) {
    Serial.print("Color detectado en la extrema derecha. X: ");
    Serial.println(result.xCenter);
    
    Rojolargo();
}
if (result.ID == 3 && result.height>62 && result.xOrigin > 270 && senna <= 0) {
    Serial.print("Color detectado en la extrema derecha. X: ");
    Serial.println(result.xCenter);
    
        Rojolargo();
}


 
//FLANCO IZQUIERDA
  else if (result.ID == 1 && result.height>70 && result.xOrigin >20 && result.xOrigin < 160  && senna <= 0){
    Serial.println("------------- low red -----------");//avoid less for right izquierda
      rojoizquierda();
          delay(winnie);
  }

  //FLANCO IZQUIERDA
  else if (result.ID == 2 && result.height>70 && result.xOrigin >20 && result.xOrigin < 160 && senna <= 0){
    Serial.println("------------- low led red -----------");//avoid less for right
      rojoizquierda();
          delay(winnie);
  }
  else if (result.ID == 3 && result.height>70 && result.xOrigin >20 && result.xOrigin < 160 && senna <= 0) {
    Serial.println("------------- low red -----------");//avoid less for right izquierda
      rojoizquierda();
          delay(winnie);
  }
// Si detecta el ID 1 (Rojo) O el ID 5 (Verde) Y está muy a la izquierda (X < 80)
if (result.ID == 1 && result.height>70 && result.xOrigin >0 && result.xOrigin < 20 && senna <= 0) {
    Serial.print("Color detectado en la extrema izquierda. X: ");
    Serial.println(result.xCenter);
   esquivarObjetoMuyIzquierda();
}
if (result.ID == 3 && result.height>70 && result.xOrigin >0 && result.xOrigin < 20 && senna <= 0) {
    Serial.print("Color detectado en la extrema izquierda. X: ");
    Serial.println(result.xCenter);
    esquivarObjetoMuyIzquierda();
}
if (result.ID == 2 && result.height>70 && result.xOrigin >0 && result.xOrigin < 30 && senna <= 0) {
    Serial.print("Color detectado en la extrema izquierda. X: ");
    Serial.println(result.xCenter);
   esquivarObjetoMuyIzquierda();
}

//VERDE IZQUIERDA
  else if (result.ID == 4 && result.height>50 && result.xOrigin >50 && result.xOrigin < 160 && senna <= 0){
    Serial.println("-------------green with LED-----------"); //avoid for left
     verdeizquierda();
          delay(winnieV);
  }

  //VERDE IZQUIERDA
  else if (result.ID == 5 && result.height>50 && result.xOrigin >50 && result.xOrigin < 160 && senna <= 0){
    Serial.println("-------------green with LED-----------"); //avoid for left
     verdeizquierda();
          delay(winnieV);
  }

//VERDE IZQUIERDA
  else if (result.ID == 6  && result.height>50 && result.xOrigin >50 && result.xOrigin < 160 && senna <= 0){//izquierdo
    Serial.println("-------------green-----------"); //avoid for left
    verdeizquierda();
       delay(winnieV);
  }


   //VERDE DERECHA
   else if (result.ID == 4 && result.height>70 && result.xOrigin >= 160 && result.xOrigin <290 && senna <= 0){//flanco derecho
    Serial.println("------------- low green with LED -----------"); //avoid less for left
    verdederecha();
          delay(winnieV);
   }
   //VERDE DERECHA
   else if (result.ID == 5 && result.height>70 && result.xOrigin >= 160 && result.xOrigin <290 && senna <= 0){//flanco derecho
    Serial.println("------------- low green with LED -----------"); //avoid less for left
    verdederecha();
          delay(winnieV);
   }


   //VERDE DERECHAA
   else if (result.ID == 6 && result.height>70 && result.xOrigin >= 160 && result.xOrigin <290 && senna <= 0){
  Serial.println("------------- low green -----------"); //avoid less for left
    verdederecha();
          delay(winnieV);
   }
//CORTO CORTO
if (result.ID == 4 && result.height>70 && result.xOrigin > 290 && senna <= 0) {
    Serial.print("Color detectado en la extrema derecha. X: ");
    Serial.println(result.xCenter);
    
    esquivarObjetoMuyDerecha();
}
if (result.ID == 5 && result.height>70 && result.xOrigin > 290 && senna <= 0) {
    Serial.print("Color detectado en la extrema derecha. X: ");
    Serial.println(result.xCenter);
    
    esquivarObjetoMuyDerecha();
}
if (result.ID == 6 && result.height>50 && result.xOrigin > 290 && senna <= 0) {
    Serial.print("Color detectado en la extrema derecha. X: ");
    Serial.println(result.xCenter);
    
    esquivarObjetoMuyDerecha();
}
// Largo Largo
if (result.ID == 4 && result.height>54 && result.xOrigin > 1 && result.xOrigin < 50 && senna <= 0) {
    Serial.print("Color detectado en la extrema izquierda. X: ");
    Serial.println(result.xCenter);
    Verdelargo();
}
if (result.ID == 5 && result.height>54 && result.xOrigin > 1 && result.xOrigin < 50 && senna <= 0) {
    Serial.print("Color detectado en la extrema izquierda. X: ");
    Serial.println(result.xCenter);
    Verdelargo();
}
if (result.ID == 6 && result.height>54 && result.xOrigin > 1 && result.xOrigin < 50 && senna <= 0) {
    Serial.print("Color detectado en la extrema izquierda. X: ");
    Serial.println(result.xCenter);
    Verdelargo();
 }

 //Antihorario

 //ID1, ID4 DETECCION ROJO
    if (result.ID == 1 && result.height>52 && result.xOrigin >= 160 && result.xOrigin <280  && grasa > 0 && lewis >= 0) {
        Serial.println("-------------red -----------");//avoid for right
      rojoderechaA();
          delay(winnie);
  }


    //FLANCO DERECHO
     else if (result.ID == 2 && result.height>52 && result.xOrigin >= 160 && result.xOrigin <280  && grasa > 0 && lewis >= 0) {
        Serial.println("-------------red -----------");//avoid for right
      rojoderechaA();
          delay(winnie);
  }  

     //FLANCO DERECHO
     else if (result.ID == 3 && result.height>52 && result.xOrigin >= 160 && result.xOrigin <280  && grasa > 0 && lewis >= 0) {
        Serial.println("-------------red -----------");//avoid for right
      rojoderechaA();
          delay(winnie);
  }  
  //Largo Largo 
  if (result.ID == 1 && result.height>70 && result.xOrigin > 280  && grasa > 0 && lewis >= 0) {
    Serial.print("Color detectado en la extrema derecha. X: ");
    Serial.println(result.xCenter);
    
        RojolargoA();
}
if (result.ID == 2 && result.height>70 && result.xOrigin > 280  && grasa > 0 && lewis >= 0) {
    Serial.print("Color detectado en la extrema derecha. X: ");
    Serial.println(result.xCenter);
    
    RojolargoA();
}
if (result.ID == 3 && result.height>70 && result.xOrigin > 280  && grasa > 0 && lewis >= 0) {
    Serial.print("Color detectado en la extrema derecha. X: ");
    Serial.println(result.xCenter);
    
        RojolargoA();
}
//VERDE IZQUIERDA
  else if (result.ID == 4 && result.height>50 && result.xOrigin >50 && result.xOrigin < 160 && grasa > 0 && lewis >= 0){
    Serial.println("-------------green with LED-----------"); //avoid for left
     verdeizquierda();
          delay(winnieV);
  }

  //VERDE IZQUIERDA
  else if (result.ID == 5 && result.height>50 && result.xOrigin >50 && result.xOrigin < 160 && grasa > 0 && lewis >= 0){
    Serial.println("-------------green with LED-----------"); //avoid for left
     verdeizquierda();
          delay(winnieV);
  }

//VERDE IZQUIERDA
  else if (result.ID == 6  && result.height>50 && result.xOrigin >50 && result.xOrigin < 160 && grasa > 0 && lewis >= 0){//izquierdo
    Serial.println("-------------green-----------"); //avoid for left
    verdeizquierda();
       delay(winnieV);
  }


   //VERDE DERECHA
   else if (result.ID == 4 && result.height>70 && result.xOrigin >= 160 && result.xOrigin <290 && grasa > 0 && lewis >= 0){//flanco derecho
    Serial.println("------------- low green with LED -----------"); //avoid less for left
    verdederecha();
          delay(winnieV);
   }
   //VERDE DERECHA
   else if (result.ID == 5 && result.height>70 && result.xOrigin >= 160 && result.xOrigin <290 && grasa > 0 && lewis >= 0){//flanco derecho
    Serial.println("------------- low green with LED -----------"); //avoid less for left
    verdederecha();
          delay(winnieV);
   }


   //VERDE DERECHAA
   else if (result.ID == 6 && result.height>70 && result.xOrigin >= 160 && result.xOrigin <290 && grasa > 0 && lewis >= 0){
  Serial.println("------------- low green -----------"); //avoid less for left
    verdederecha();
          delay(winnieV);
   }
//CORTO CORTO
if (result.ID == 4 && result.height>70 && result.xOrigin > 290 && grasa > 0 && lewis >= 0) {
    Serial.print("Color detectado en la extrema derecha. X: ");
    Serial.println(result.xCenter);
    
    esquivarObjetoMuyDerecha();
}
if (result.ID == 5 && result.height>70 && result.xOrigin > 290 && grasa > 0 && lewis >= 0) {
    Serial.print("Color detectado en la extrema derecha. X: ");
    Serial.println(result.xCenter);
    
    esquivarObjetoMuyDerecha();
}
if (result.ID == 6 && result.height>50 && result.xOrigin > 290 && grasa > 0 && lewis >= 0) {
    Serial.print("Color detectado en la extrema derecha. X: ");
    Serial.println(result.xCenter);
    
    esquivarObjetoMuyDerecha();
}
// Largo Largo
if (result.ID == 4 && result.height>54 && result.xOrigin > 1 && result.xOrigin < 50 && grasa > 0 && lewis >= 0) {
    Serial.print("Color detectado en la extrema izquierda. X: ");
    Serial.println(result.xCenter);
    Verdelargo();
}
if (result.ID == 5 && result.height>54 && result.xOrigin > 1 && result.xOrigin < 50 && grasa > 0 && lewis >= 0) {
    Serial.print("Color detectado en la extrema izquierda. X: ");
    Serial.println(result.xCenter);
    Verdelargo();
}
if (result.ID == 6 && result.height>54 && result.xOrigin > 1 && result.xOrigin < 50 && grasa > 0 && lewis >= 0) {
    Serial.print("Color detectado en la extrema izquierda. X: ");
    Serial.println(result.xCenter);
    Verdelargo();
 }

}

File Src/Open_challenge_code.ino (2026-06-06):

#include <NewPing.h> // Biblioteca para el sensor ultrasónico
#include <Servo.h> // Biblioteca para el servo
Servo myservo; // Crea un objeto servo para controlar el servo

int centro = 97;
int centroA =98;
int centroH = 96;
int carSpeed = 65;
int carSpeedCurvas = 90;

//--------------- driver
#define ENA 5
#define IN1 8
#define IN2 7

//--------------- Ultrasonics
#define TRIGGER_PIN  A0  // Arduino pin tied to trigger pin on the ultrasonic sensor.
#define ECHO_PIN     A1  // Arduino pin tied to echo pin on the ultrasonic sensor.

#define TRIGGER_PIN2  A2  // Arduino pin tied to trigger pin on the ultrasonic sensor.
#define ECHO_PIN2 A3  // Arduino pin tied to echo pin on the ultrasonic sensor.

#define TRIGGER_PIN3  A4  // Arduino pin tied to trigger pin on the ultrasonic sensor.
#define ECHO_PIN3 A5  // Arduino pin tied to echo pin on the ultrasonic sensor.

#define MAX_DISTANCE 400 // Maximum distance we want to ping for (in centimeters). Maximum sensor distance is rated at 400-500cm.

  NewPing sonar(TRIGGER_PIN, ECHO_PIN, MAX_DISTANCE);// NewPing setup of pins and maximum distance.
  NewPing lsonar(TRIGGER_PIN2, ECHO_PIN2, MAX_DISTANCE); // NewPing setup of pins and maximum distance.
  NewPing Rsonar(TRIGGER_PIN3, ECHO_PIN3, MAX_DISTANCE); // NewPing setup of pins and maximum distance.

int rightDistance = 0, leftDistance = 0, middleDistance = 0;


void forward(){

  digitalWrite(IN1,HIGH); //set IN1 hight level
  digitalWrite(IN2,LOW);  //set IN2 low level
  Serial.print("Forward- ");//send message to serial monitor
  Serial.println(middleDistance);
}


//void back(){
//digitalWrite(ENA,HIGH);
//digitalWrite(IN1,LOW);
//digitalWrite(IN2,HIGH);
//Serial.print("B ");
//}
  void freno(){
  analogWrite(ENA,50);
  digitalWrite(IN1,LOW);
  digitalWrite(IN2,HIGH);
  }

void stop(){
  digitalWrite(IN1,LOW); //set IN1 hight level
  digitalWrite(IN2,LOW);  //set IN2 low level
}

void izquierda(){//antihorario
  myservo.write(60);   //  Cerca, ángulo 0
  analogWrite(ENA,carSpeedCurvas);
    delay(680);
    myservo.write(centroA);
  }

void derecha(){//horario
    myservo.write(140); //  Cerca, ángulo 0
    analogWrite(ENA,carSpeedCurvas);
    delay(465);
         myservo.write(centroH);
  }


void setup() {
  Serial.begin(9600);

  myservo.attach(3);
  pinMode(IN1,OUTPUT);//before useing io pin, pin mode must be set first
  pinMode(IN2,OUTPUT);
  pinMode(ENA,OUTPUT);
  //pin sentido
 // pinMode(41, INPUT);
  //pinMode(40, OUTPUT);
  //digitalWrite (40, HIGH);
}       
int pepe = 0;
int tilin = 0;
int grasa = 0;
int lewis = 0;
int lecrer = 0;
void loop(){

analogWrite(ENA, carSpeed);
if (pepe==0){
  myservo.write(75);
  delay(1175);
  myservo.write(centro);
 // stop();
  
  delay(1000);
  forward(); 

  forward();
  pepe++;
}

forward();

if (pepe>12){
  delay(1);
  forward();
   myservo.write(centro);
  delay(1600);
  stop();
  delay(1000000000);
}


middleDistance = sonar.ping_cm();
leftDistance = lsonar.ping_cm();
rightDistance = Rsonar.ping_cm();

if (middleDistance <= 32 && middleDistance > 20){
Serial.println(middleDistance);
forward();
  pepe++;

 
  Serial.println(leftDistance);
  Serial.println(rightDistance);

   //  if leftdistance > 50 = clockwise       
  //if (leftDistance <= 80 && leftDistance > 1){
    //if (d>igitalRead(41)){
   if (leftDistance <= rightDistance && grasa == 0){
      tilin++;
      lecrer++;
   }
   else if (leftDistance > rightDistance && tilin == 0){
    grasa++;
    lewis++;
   }

    if (tilin > 0 && grasa == 0 && lecrer >= 0){

      derecha();


    }

//sin pin antihorario    
 else if (grasa > 0 && lewis >= 0){
   
  izquierda();
}
 }   
   if (leftDistance <= 9 && leftDistance > 1 && pepe > 0 ){
  myservo.write(120);   //  Cerca, ángulo 0
   delay(30);
    myservo.write(centroH);
    }
   if(rightDistance <= 9 && rightDistance > 1 && pepe > 0){
     myservo.write(70);   //  Cerca, ángulo 0
    delay(30);
    myservo.write(centroA);
}
delay(100);


}

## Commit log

2026-04-22 Movilidad y diseño mecanico
    En este archivo el equipo explica el sistema de movilidad de Trivilyn. El porque se tomaron ciertas decisiones en en la realización de su estructura y diseño.
    [SOPORTETRENDELANTEROREXBOT2.0.stl]
2026-04-22 Se elimino porque era una prueba.
    [SOPORTETRENDELANTEROREXBOT2.0.stl]
2026-04-23 Movilidad y diseño mecánico.
    En este archivo se evidencian las soluciones que aplico el equipo para el diseño y movilidad Trivilyn3.0
    [SOPORTETRENDELANTEROREXBOT2.0.stl]
2026-05-05 se elimina pq se subio como prueba
    [SOPORTETRENDELANTEROREXBOT2.0.stl]
2026-05-06 Fue un error de carga
2026-05-06 Archivos CAD de Trivilyn3.0
    En este commit se encuentran todos los archivos CAD necesarios para la elaboración y construcción de Trivilyn3.0
    [Primer Piso Trivilyn3.0.stl, Segundo Piso Trivilyn3.0.stl, Soporte Caja de Engranajes Trivilyn3.0.stl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]
2026-05-06 Fix typo in README for 'Archivos CAD'
2026-05-06 Se eliminaron pra hacer una prueba
    [Primer Piso Trivilyn3.0.stl, Segundo Piso Trivilyn3.0.stl, Soporte Caja de Engranajes Trivilyn3.0.stl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]
2026-05-13 Error de prueba
    Updated project summary to reflect changes in track size.
2026-06-07 Rename Riel macho Cola de milano.stl to Riel macho Cola de milano.stl
    [Riel macho Cola de milano.stl]
2026-06-18 Add Assembly Manual for Trivilyn 3.0
2026-06-20 Enhance README with 3D printing and manufacturing details
    Added a new section on 3D printing and manufacturing optimization, including details on design tools, slicing profiles, and mechanical analysis of the Gyroid fill pattern.
2026-06-21 Fix links in README for Assembly Manual and Trivilyn 360
2026-06-21 Enhance README with analysis and tribology sections
    Added sections on fatigue resistance analysis and tribological interface model to enhance understanding of mechanical design.
2026-06-21 Update Assembly Manual.md
2026-06-24 Enhance README with motor justification and wiring standards
    Added justifications for motor selection and detailed analysis of gear train dynamics. Updated wiring color coding standards and clarified power distribution architecture.
2026-06-27 Enhance README with sensor distribution details
    Added sections on sensor distribution and geometry for the track, including details on ultrasonic sensor placement and camera positioning for obstacle avoidance.
2026-07-02 Create Archivos CAD.md
2026-07-02 Add CAD files documentation for Trivilyn 3.0
    Added documentation for 3D modeling and CAD files for Trivilyn 3.0, including manufacturing parameters, structural components breakdown, and assembly guidelines.
2026-07-02 Refactor section headers and update file formats
    Removed emoji from section headers and updated file description to specify only '.STL' format.
2026-08-19 Refactor ultrasonic sensor and servo control logic
    Updated ultrasonic sensor handling and servo control logic. Refactored variable names and improved code structure for clarity.
2026-08-24 Add installation guide for Trivilyn 3.1
    Added detailed installation guide for Trivilyn 3.1, including hardware requirements, IDE setup, library installations, electrical verification, camera configuration, sensor setup, wiring verification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
2026-08-24 Add installation guide to README
    Added installation guide for ESP32 firmware setup.
